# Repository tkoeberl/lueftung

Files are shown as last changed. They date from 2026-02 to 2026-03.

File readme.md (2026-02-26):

# 🌀 Decentralized Ventilation Controller

This controller operates decentralized ventilation systems (e.g. Ventomaxx) using an ESP32 and ESPHome.

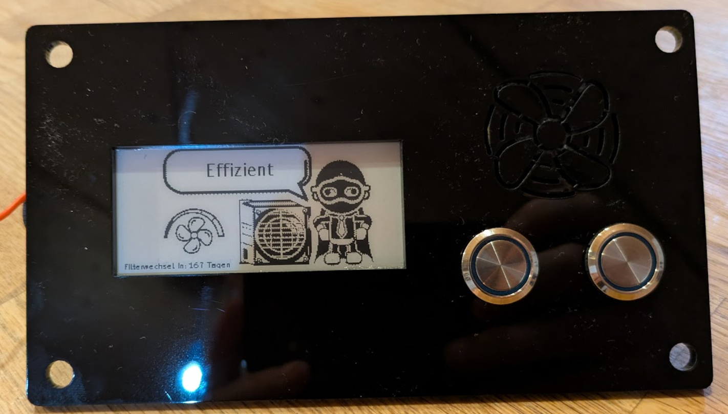
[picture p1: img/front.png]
front
  
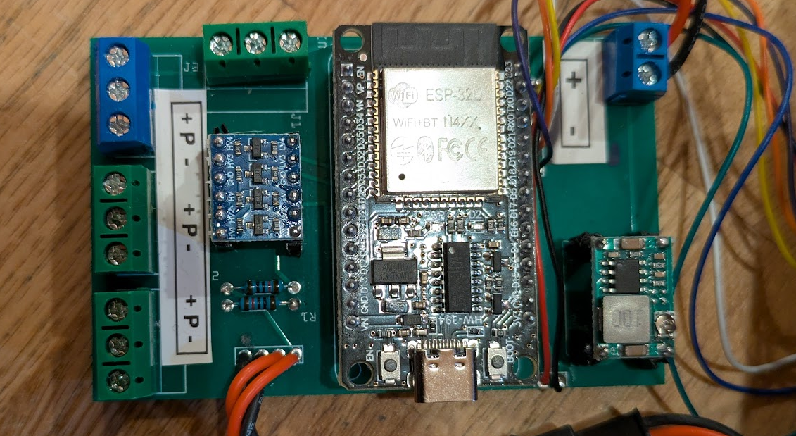
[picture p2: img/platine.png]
platine


---

## 🔧 Hardware

- PCB: (fritzing/lueftung.fzz, from here: https://passport.jlcpcb.com/)
- ESP32 (https://de.aliexpress.com/item/1005008010626661.html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)
- 2.9" e-paper display (https://de.aliexpress.com/item/1005004644515880.html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)
- Voltage regulator (https://de.aliexpress.com/item/1005006786970258.html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)
- Level shifter (https://www.amazon.de/dp/B082F6BSB5?ref_=ppx_hzsearch_conn_dt_b_fed_asin_title_1)
- Misc. small components  

---

## 💾 Software

Flash the firmware using **[ESPHome](https://esphome.io/)**.

---

# ⚙️ Ventilation Programs – Functional Description

The controller provides **four programs** that manage the interaction of **four fans** depending on the desired airflow behavior.

All programs react to the selected **fan level (0–5)**, which affects:

- Fan speed (PWM ratio)
- Direction switching interval
- Overall intensity

---

## 🧠 General Control Concept

- **Number of fans:** 4  
- **Control method:** PWM (0–100%)  
- **Fan level:** `0 … 5`

### Level influence

- Defines the **PWM ratio** → `current_percentage`
- Defines the **direction change interval`

### Operation

Control via:

- Home Assistant (select + slider)
- Two hardware buttons  
  - Program  
  - Level
- E-paper display for status output

---

## 🎚️ Fan Levels

| Level | PWM Output | Switching Interval |
|---:|---:|---:|
| 0 | 50 % | almost off / static |
| 1 | 40 % | 70 s |
| 2 | 30 % | 65 s |
| 3 | 20 % | 60 s |
| 4 | 10 % | 55 s |
| 5 | 1 % | 50 s |

> The higher the level, the more **dynamic and intensive** the ventilation.

---

# 🧭 Programs

---

## ↔️ Cross Forward (`cross_1`)

**Description:**  
Opposing fan pairs run offset to generate a **directed cross-flow**.

**Logic:**

- Fans **1 & 3** → `1 − percentage`  
- Fans **2 & 4** → `percentage`

➡ Produces a constant airflow in a fixed direction.

**Typical use:**

- Continuous background ventilation  
- Gentle air exchange without direction changes  

---

## ↔️ Cross Backward (`cross_2`)

**Description:**  
Same as *Cross Forward*, but with **reversed airflow direction**.

**Logic:**

- Fans **1 & 3** → `percentage`  
- Fans **2 & 4** → `1 − percentage`

➡ Airflow is exactly opposite to `cross_1`.

**Typical use:**

- Change airflow direction  
- Prevent one-sided ventilation  

---

## 🔄 Efficient Mode (`efficient`)

**Description:**  
Alternating cross-ventilation with periodic direction change.  
**Balanced and energy-efficient.**

**Sequence:**

1. **Phase A**
   - Fans 1 & 3 → `1 − percentage`
   - Fans 2 & 4 → `percentage`
2. Wait `current_interval`
3. **Phase B**
   - Fans 1 & 3 → `percentage`
   - Fans 2 & 4 → `1 − percentage`
4. Repeat forever

➡ Ensures uniform air exchange without a permanent main airflow direction.

**Typical use:**

- Living spaces  
- Continuous operation  
- Energy-saving mode  

---

## 💨 Boost Ventilation (`intensive`)

**Description:**  
Time-controlled combination of **efficient mode** and **ventilation pause** for maximum air exchange.

**Cycle:**

1. Start **Efficient mode**
2. Run for **15 minutes**
3. Stop ventilation
4. **Pause for 105 minutes**
5. Repeat forever

➡ Simulates automatic periodic boost ventilation.

**Typical use:**

- Bathroom  
- Kitchen  
- High humidity rooms  
- Automatic fresh-air cycles  

---

# 🖥️ Display & Feedback

The e-paper display shows:

- Active program (text)
- Fan level (icons 0–5)

Additionally:

- Each fan’s current PWM output is exposed as a **percentage sensor**.

---

# 📊 Program Comparison

| Program | Direction | Alternating | Intensity | Typical Use |
|---|---|---|---|---|
| cross_1 | fixed | ❌ | low–medium | Continuous ventilation |
| cross_2 | fixed (reversed) | ❌ | low–medium | Airflow change |
| efficient | alternating | ✅ | medium | Living spaces |
| intensive | cyclic | ✅ | high | Boost ventilation |

---

## 🔁 Behavior on Changes

Changing the **program** or **fan level**:

- Stops all running scripts
- Restarts the selected ventilation profile cleanly

---

# 🏠 Home Assistant Integration

Control elements:

- Program selection
- Fan level slider
- Fan power sensors (PWM %)

---

## 📌 Notes

- Designed for decentralized ventilation units
- Optimized for quiet, balanced, and energy-efficient operation
- each vent can be conrolled by homeassistant directly to extend the programs
- no guarantee of any kind.

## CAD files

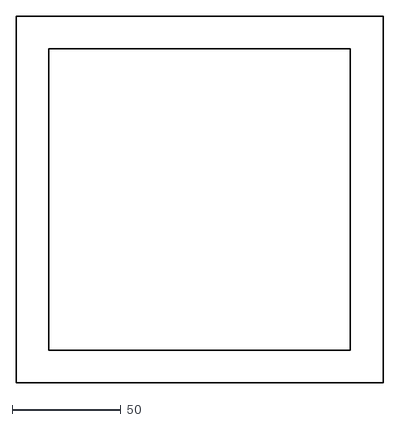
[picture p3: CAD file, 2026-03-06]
filter.dxf
169.1 x 169.0

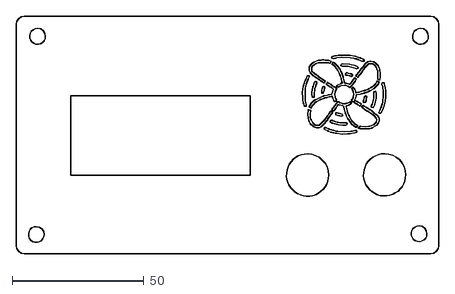
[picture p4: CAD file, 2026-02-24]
Montageplatte.dxf
160.0 x 90.0

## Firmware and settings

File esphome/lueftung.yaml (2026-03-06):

esphome:
  name: "luefter"
  friendly_name: luefter
  min_version: 2025.11.0
  name_add_mac_suffix: false
  on_boot:
    priority: -100
    then:
      - lambda: |-
          if (id(current_program).empty())
            id(current_program) = "interval";

          if (id(current_level) < 0 || id(current_level) > 5)
            id(current_level) = 0;  
      - lambda: |-
          id(program_select).publish_state(id(current_program));
          id(luefter_level).publish_state(id(current_level));
      - script.execute: script_update


esp32:
  board: esp32dev
  framework:
    type: esp-idf
    advanced:
      minimum_chip_revision: "3.1"


wifi:
  #ssid: !secret wifi_ssid
  #password: !secret wifi_password
  # Enable fallback AP if WiFi fails
  ap:
    ssid: "Windfried"
    # password: "optional_password"

captive_portal:

web_server:
  port: 80

mdns:
  disabled: false

logger:
  logs: 
    component: WARN
  level: WARN

api:
    services:
    - action: set_luefter_level
      variables:
        luefter: int
        level: float
      then:
        - script.execute:
            id: set_luefter_level
            luefter: !lambda 'return luefter;'
            level: !lambda 'return level;'

ota:
  platform: esphome

globals:
  - id: current_program
    type: std::string
    restore_value: true
  - id: last_program
    type: std::string
    restore_value: true    
  - id: current_level
    type: int
    restore_value: true
  - id: last_level
    type: int
    restore_value: true    
  - id: current_percentage
    type: float
    restore_value: false  # Kein Wert wird beim Neustart wiederhergestellt
    initial_value: '0'
  - id: current_interval
    type: int
    restore_value: false  # Kein Wert wird beim Neustart wiederhergestellt
    initial_value: '0'  
  - id: mode_index
    type: int
    initial_value: '0'    
  - id: current_luefter_1_pwm
    type: float
    restore_value: false  # Kein Wert wird beim Neustart wiederhergestellt
    initial_value: '0'
  - id: current_luefter_2_pwm
    type: float
    restore_value: false  # Kein Wert wird beim Neustart wiederhergestellt
    initial_value: '0'
  - id: current_luefter_3_pwm
    type: float
    restore_value: false  # Kein Wert wird beim Neustart wiederhergestellt
    initial_value: '0'        
  - id: current_luefter_4_pwm
    type: float
    restore_value: false  # Kein Wert wird beim Neustart wiederhergestellt
    initial_value: '0' 
  - id: betrieb_seconds
    type: uint32_t
    restore_value: true
    initial_value: '0'    
  - id: filter_limit_hours
    type: float
    restore_value: false
    initial_value: '4000.0'    

# Definiere die PWM-Ausgänge für die Lüfter
output:
  - platform: ledc
    id: luefter_1_pwm
    pin: GPIO25
    frequency: 2000Hz 
    inverted: false
  - platform: ledc
    id: luefter_2_pwm
    pin: GPIO26
    frequency: 2000Hz 
    inverted: false
  - platform: ledc
    id: luefter_3_pwm
    pin: GPIO32
    frequency: 2000Hz 
    inverted: false    
  - platform: ledc
    id: luefter_4_pwm
    pin: GPIO33
    frequency: 2000Hz 
    inverted: false

button:
  - platform: template
    name: "reboot"
    on_press:
      - logger.log: "Manual reboot"
      - delay: 300ms
      - lambda: |-      
          ESP_LOGI("reboot", "current_program: %s , current_level: %d", id(current_program).c_str(), id(current_level) );
      - button.press: reboot_button
  - platform: restart
    id: reboot_button
    internal: true  # Dieser Button wird nicht in Home Assistant angezeigt
  - platform: template
    name: "Betriebsstunden zurücksetzen"
    icon: "mdi:restart"
    on_press:
      - lambda: |-
          id(betrieb_seconds) = 0;  
          id(script_update).execute();
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

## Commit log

2026-01-16 initial release
    [lueftung.fzz]
2026-01-16 initial release 2
    [lueftung.fzz]
2026-02-24 Update PCB link in readme.md
    Added source link for PCB file in the hardware section.
2026-02-26 Fix luefter name and friendly name in configuration
    [lueftung.yaml]
2026-03-06 Update display text for 'efficient' program in luefter configuration
    [filter.dxf]
